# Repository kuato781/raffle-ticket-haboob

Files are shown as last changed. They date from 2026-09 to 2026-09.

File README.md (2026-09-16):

# Raffle Ticket Haboob

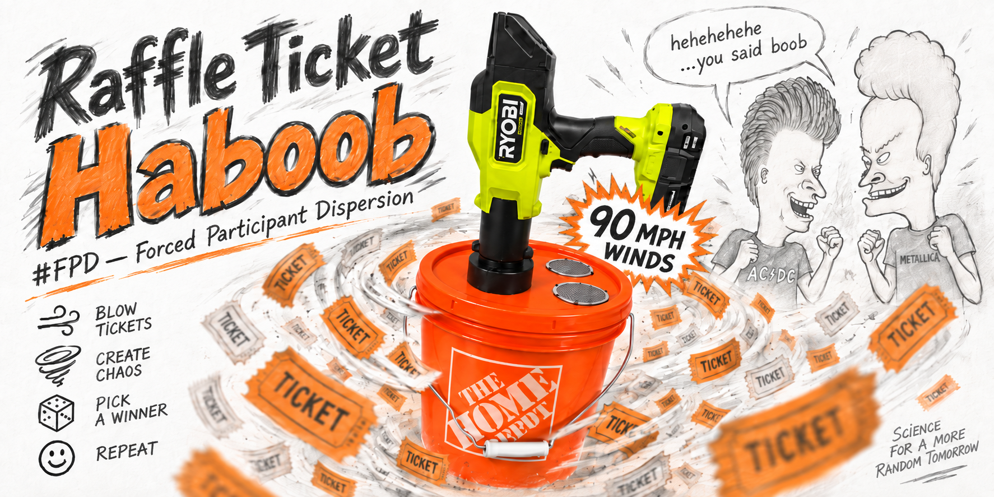
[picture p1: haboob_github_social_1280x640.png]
Raffle Ticket Haboob


A 3D-printed, blower-powered raffle-ticket mixer built around a 2-gallon bucket, a removable lid assembly, and a compact RYOBI cordless blower.

The goal is simple: break up the ticket clumps that survive ordinary bucket shaking and force the whole ticket mass into motion before a drawing.

The operating principle is **#FPD — Forced Participant Dispersion**.

In less formal engineering language: **fuck your clumps.**

## What It Does

The Haboob injects a high-volume air stream into a raffle bucket through a bayonet-style receiver mounted in the lid. Three screened exhaust openings allow air to escape while printed internal baffles reduce the tendency for tickets to plaster themselves directly against the screens.

The blower is used in short pulses rather than held continuously. Each pulse lifts and redistributes the ticket mass, then lets it settle before the next pulse.

The project was physically prototyped and iterated using actual raffle tickets, including internal video taken from inside the bucket during testing.

> **Airflow note:** The project artwork references **90 MPH winds**. That number is a rough idealized estimate of average air velocity through the approximately 2.25-inch receiver bore at 220 CFM. It is not a measured ticket velocity or a calibrated performance rating. The RYOBI blower itself is manufacturer-rated up to 140 MPH.

## Designed Blower

The receiver geometry was designed and physically fit-tested with the:

**RYOBI 18V ONE+ HP Compact Brushless 220 CFM Blower — model PSBLB01B**

- 220 CFM rated airflow
- up to 140 MPH manufacturer-rated airspeed
- product page: https://www.ryobitools.com/products/46396047137

Other blowers may work, but the bayonet receiver, bore, lug locations and clearances were designed around this specific tool. Using another blower may require changes to the receiver geometry.

## Major Components

The lid assembly consists of:

- threaded blower receiver;
- knurled underside locknut;
- removable bayonet storage plug;
- three round mesh vent screens;
- three internal anti-ingestion baffles;
- nine M2.5 × 4 mm button-head screws;
- nine M2.5 heat-set inserts;
- one reusable layout/drill template.

The removable threaded receiver and vent hardware allow the lid components to be taken off for storage so the buckets and lids can still nest/stack normally.

## Shopping List

| Item | Notes | Link |
|---|---|---|
| Round screen vent covers | Three per lid | https://www.amazon.com/gp/product/B0F9F76M15/ref=ox_sc_act_title_1 |
| M2.5 heat-set inserts | **M2.5 × 4 × 3.5** — M2.5 thread, 4 mm length, 3.5 mm OD | https://www.amazon.com/dp/B0F2N8QY45 |
| Awl | Useful for transferring template hole locations | https://www.amazon.com/dp/B0D6NJ2XSF |
| Hole saw set | Includes the required 2-1/2 in and 2-1/8 in sizes | https://www.harborfreight.com/34-in-to-5-in-carbon-steel-hole-saw-set-18-piece-57524.html |
| Home Depot orange 2-gallon bucket | Orange bucket option | https://www.homedepot.com/p/The-Home-Depot-2-gal-Orange-paint-Bucket-PN0192/321367180 |
| Home Depot orange lid | Matching orange lid | https://www.homedepot.com/p/2-Gal-Orange-Lid-RG502LHD/332526779 |
| Leaktite white 2-gallon bucket | White bucket option | https://www.homedepot.com/p/Leaktite-2-Gallon-White-Paint-Bucket-2GL-WHITE-PAIL/202264039 |
| Leaktite 2-gallon lid | Matching white lid | https://www.homedepot.com/p/Leaktite-2-gal-Bucket-Lid-210655/202264036 |
| M2.5 × 4 mm button-head screws | Nine per lid | Source locally or from your preferred hardware supplier |

See also: [`buy-list/README.md`](buy-list/README.md).

## Printed Parts

Current printable files are in [`stl-scad/`](stl-scad/):

- blower receiver;
- knurled locknut;
- bayonet storage plug;
- vent baffle;
- layout/drill template;
- editable OpenSCAD sources.

Exact current dimensions, clearances and the iteration history are documented in [`documentation/design-notes/README.md`](documentation/design-notes/README.md).

A Bambu Studio project is also included in [`bambu-sudio-3mf/`](bambu-sudio-3mf/).

The repository intentionally has **no V1/V2 directory split**. Unlike the Spektrum iX14 stand project, this project has one current physically validated design rather than parallel legacy/current versions.

## Lid Layout

### Receiver hole

Cut one **2-1/2 inch** hole for the blower receiver.

The tested layout places the receiver-hole center approximately **1-3/4 inches from the outside lid lip**.

### Vent holes

Cut three **2-1/8 inch** holes for the vent screens.

The included 82 mm layout/drill template is designed to make this repeatable:

1. Print **three templates** if possible.
2. Place all three templates flat-side-up on the lid.
3. Arrange them around the receiver location so the full 82 mm baffle footprints clear one another and have the spacing/orientation you want.
4. Mark the center hole in each template.
5. Cut the three 2-1/8 inch vent holes.
6. Flip the template over.
7. Insert the raised locating boss/lip into each finished vent hole.
8. Use the three guide holes to mark the M2.5 mounting screw locations.

Using the same template for both layout and bolt-hole transfer makes multiple lids much easier to reproduce with consistent geometry.

## Assembly

Detailed instructions are in [`documentation/assembly-instructions/README.md`](documentation/assembly-instructions/README.md).

High-level sequence:

1. Print the receiver, locknut, plug, three baffles and layout/drill templates.
2. Install the M2.5 heat-set inserts in the three bosses on each baffle.
3. Lay out and cut the 2-1/2 inch receiver hole.
4. Use three layout templates to establish the three 2-1/8 inch vent positions with enough clearance between the full baffle footprints.
5. Cut the three vent holes.
6. Flip/key the template into each finished vent hole and mark the three M2.5 screw holes.
7. Install the threaded receiver from the top and secure it below the lid with the knurled locknut.
8. Install the three round mesh vent screens.
9. Install one baffle beneath each vent using three M2.5 × 4 mm button-head screws.

The current baffle uses three heat-set-insert mounting bosses and a perimeter cage. The contact ribs intentionally stand slightly proud of the bosses so tightening the screws preloads the rib tops against the underside of the lid and reduces ticket-ingestion gaps.

## Operation

1. Make sure the lid is fully seated on the bucket.
2. For event use, adding duct tape around the lid/bucket seam is recommended as secondary retention.
3. Lock the blower into the bayonet receiver.
4. Keep the assembly stable and the lid restrained. If it can be done safely, steady downward pressure on the lid can help control movement, but **do not rely on hand pressure as the only lid-retention method**.
5. **Pulse** the blower rather than holding it continuously.
6. Let the tickets lift, circulate and settle between pulses.
7. Remove the blower when mixing is complete.

The airflow is intentionally substantial. Do not operate the system with an unsecured lid, damaged printed parts, loose hardware or bystanders positioned where a lid or loose component could strike them.

## Drawing Workflow

The baffle system greatly reduces tickets getting trapped against the vent screens, but the project is not intended to guarantee that absolutely zero tickets can ever lodge between a baffle and the lid.

Before a final drawing:

1. Open the bucket.
2. Inspect the underside of the lid and all three baffles.
3. Remove any ticket that may have lodged there and return it to the bucket.
4. Give the tickets one final manual stir.
5. Draw normally.

That last inspection/manual stir is the practical final safeguard against the occasional straggler.

## End-of-Day Storage

When the bucket is being stored with tickets still inside:

- remove the blower;
- install the bayonet plug in the receiver opening;
- confirm the lid is fully seated before moving or storing the bucket.

For compact storage after the event, the lid hardware can be removed and placed inside each bucket. The buckets and bare lids can then nest/stack into one another.

## Product Photos

Physical-build product images are in [`documentation/product-images/`](documentation/product-images/).

The set includes:

- receiver, locknut and plug;
- baffle and drill-template hardware;
- mesh vent screens;
- completed lid;
- assembled bucket;
- blower installed in the receiver;
- bucket with the storage plug installed.

A contact sheet is included as [`00-raffle-ticket-haboob-contact-sheet.png`](documentation/product-images/00-raffle-ticket-haboob-contact-sheet.png).

## Development / Test Videos

Internal testing videos are in [`documentation/videos/`](documentation/videos/):

- [`haboob-bottom-view.mov`](documentation/videos/haboob-bottom-view.mov)
- [`haboob-side-view.mov`](documentation/videos/haboob-side-view.mov)

The internal camera testing was deliberately low-tech: an iPhone was taped inside the bucket so the ticket behavior could be observed during actual blower operation.

Those tests exposed two useful problems that drove the final baffle design:

- tickets could plaster directly against the vent screens;
- tickets could sometimes slip into the gap between an early baffle and the lid.

The final larger baffle geometry clears the screen retaining tabs, uses a cage around the perimeter and adds mechanical preload against the lid.

## Development History

This project followed the same process as the other Arroyo 3D-printing projects:

**measure → model → print → physically test → revise**

The major progression was:

1. Prove that the RYOBI blower could lock into a printed receiver.
2. Convert the receiver to a removable threaded bulkhead so lids could still stack.
3. Add a removable bayonet plug for overnight/event storage.
4. Add three screened exhaust vents to relieve lid pressure.
5. Add simple standoff baffles after tickets were observed plastering against the screens.
6. Add a perimeter cage after tickets were observed entering the open annular gap.
7. Add heat-set inserts and screw mounting so baffle height would be repeatable instead of depending on hot glue.
8. Enlarge the baffle clear zone to avoid the four metal retaining tabs on the vent screens.
9. Add preload to the baffle contact ribs to reduce the remaining lid gap.
10. Convert the drill template into a two-sided layout/registration fixture so multiple lids can be built with repeatable spacing.

The current geometry has been physically tested with the actual bucket, screens, fasteners, inserts, tickets and RYOBI blower.

## AI-Assisted Design and Development

This project was developed with AI assistance.

AI was used to help:

- turn measurements and fit observations into printable geometry;
- iterate receiver, thread, bayonet, baffle and template designs;
- calculate rough airflow estimates;
- generate editable OpenSCAD sources and STL models;
- analyze physical-test results and revise the design;
- organize documentation and repository structure;
- clean up product photography and create project artwork.

The CAD was never treated as proof by itself. Physical fit, actual airflow behavior and event workflow got the final vote.

## Repository Organization

| Directory | Contents |
|---|---|
| `stl-scad/` | Current printable STL files plus editable OpenSCAD source |
| `bambu-sudio-3mf/` | Bambu Studio project file(s) |
| `buy-list/` | Shopping list and hardware requirements |
| `documentation/assembly-instructions/` | Detailed build and assembly procedure |
| `documentation/design-notes/` | Dimensions, clearances and development rationale |
| `documentation/product-images/` | Product photographs and contact sheet |
| `documentation/videos/` | Physical airflow/development test videos |

## Important Safety Information

This project combines 3D-printed parts, a high-output blower and a bucket lid that can become pressurized if airflow is restricted.

- Inspect all printed parts, heat-set inserts, screws, vent screens, receiver threads and bayonet features before use.
- Confirm that the lid is fully seated and positively retained before operating the blower.
- Never operate with blocked vents.
- Use short blower pulses rather than sustained operation.
- Keep faces, hands and bystanders out of any potential lid/component path.
- Stop immediately if the lid deforms excessively, hardware moves, the receiver loosens or any printed part cracks.
- Verify that your specific bucket, lid, blower and printed parts fit correctly before event use.
- Read [`DISCLAIMER.md`](DISCLAIMER.md) before building or operating the design.

This is an independent project and is not affiliated with or endorsed by RYOBI, Techtronic Industries, The Home Depot, Leaktite, Amazon or Harbor Freight.

## License

This project is provided under the [Creative Commons Attribution-NonCommercial 4.0 International License](LICENSE).

You may print, copy, share and modify the files for noncommercial purposes with attribution. Changes must be identified.

The original files and derivatives may not be sold or otherwise used commercially without separate permission from the creator.

## Why?

Because hand-shaking a bucket full of thin paper raffle tickets apparently wasn't enough.

So naturally the next step was:

**a cordless blower + custom bayonet hardware + threaded bulkhead + screened exhaust vents + anti-ingestion baffles + heat-set inserts + reusable drill fixtures + internal test footage.**

For a raffle bucket.

#FPD.

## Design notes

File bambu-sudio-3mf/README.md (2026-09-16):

# Bambu Studio Project

This directory contains the Bambu Studio project file(s) for the current Raffle Ticket Haboob parts.

Current project:

- `raffle_ticket_haboob_layout_drill_template_82mm_lipped_m25_v14.3mf`

The corresponding editable OpenSCAD and STL files live in [`../stl-scad/`](../stl-scad/).

Use the 3MF as a slicer starting point, but verify printer, material, layer height, wall count and other settings for your own machine before printing.

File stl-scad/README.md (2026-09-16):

# Printable CAD Files

This directory contains the current Raffle Ticket Haboob printable models and editable OpenSCAD sources.

## Current Parts

| Part | Purpose |
|---|---|
| `raffle_ticket_haboob_receiver_threaded.*` | Threaded blower receiver / lid bulkhead |
| `raffle_ticket_haboob_knurled_locknut.*` | Underside hand-tightened receiver locknut |
| `raffle_ticket_haboob_plug.*` | Bayonet storage plug for the receiver |
| `raffle_ticket_haboob_baffle.*` | Three-screw anti-ingestion vent baffle |
| `raffle_ticket_haboob_layout_drill_template.*` | 82 mm two-sided layout and screw-hole transfer template |

The `.scad` files are the editable source. The `.stl` files are ready to import into a slicer.

## Recommended Quantity

- receiver: 1
- locknut: 1
- plug: 1
- baffle: 3
- layout/drill template: ideally 3

Printing three templates is recommended because the full 82 mm disks can be arranged simultaneously on the lid before drilling. This makes the three baffle footprints easy to space consistently and prevents overlap.

## Design Details

See [`../documentation/design-notes/README.md`](../documentation/design-notes/README.md) for the current dimensions, clearances, insert geometry and design history.

## Blower Compatibility

The receiver was designed around the **RYOBI PSBLB01B 18V ONE+ HP Compact Brushless 220 CFM Blower**.

Other blowers may require modification of the receiver bore, bayonet slot/lug geometry or overall dimensions.

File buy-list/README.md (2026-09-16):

# Raffle Ticket Haboob — Shopping List

This is the hardware and tool list used for the physically tested build.

## Core hardware

| Qty | Item | Specification / notes | Link |
|---:|---|---|---|
| 1 | 2-gallon bucket | Home Depot orange option | https://www.homedepot.com/p/The-Home-Depot-2-gal-Orange-paint-Bucket-PN0192/321367180 |
| 1 | Matching lid | Home Depot orange lid | https://www.homedepot.com/p/2-Gal-Orange-Lid-RG502LHD/332526779 |
| 1 | Alternative 2-gallon bucket | Leaktite white option | https://www.homedepot.com/p/Leaktite-2-Gallon-White-Paint-Bucket-2GL-WHITE-PAIL/202264039 |
| 1 | Matching alternative lid | Leaktite white lid | https://www.homedepot.com/p/Leaktite-2-gal-Bucket-Lid-210655/202264036 |
| 3 | Round screen vent covers | One per exhaust opening | https://www.amazon.com/gp/product/B0F9F76M15/ref=ox_sc_act_title_1 |
| 9 | Heat-set inserts | **M2.5 × 4 × 3.5** — M2.5 thread, 4 mm length, 3.5 mm OD | https://www.amazon.com/dp/B0F2N8QY45 |
| 9 | Button-head screws | **M2.5 × 4 mm** | Use preferred hardware supplier |
| 1 | RYOBI compact blower | RYOBI 18V ONE+ HP Compact Brushless 220 CFM Blower, **PSBLB01B** | https://www.ryobitools.com/products/46396047137 |

## Tools

| Item | Use | Link |
|---|---|---|
| Awl | Transfer template center and screw-hole marks | https://www.amazon.com/dp/B0D6NJ2XSF |
| Hole saw set | Provides required 2-1/2 in and 2-1/8 in cutters | https://www.harborfreight.com/34-in-to-5-in-carbon-steel-hole-saw-set-18-piece-57524.html |
| Soldering iron / insert tool | Install M2.5 heat-set inserts | Use preferred tool |
| Drill | Cut lid holes and drill screw clearances | Use preferred tool |
| Deburring knife / file | Clean plastic edges after hole-saw cuts | Use preferred tool |

## Printed parts

Print from [`../stl-scad/`](../stl-scad/):

- 1 × threaded receiver
- 1 × knurled locknut
- 1 × bayonet plug
- 3 × vent baffles
- ideally 3 × layout/drill templates

Printing three layout templates is strongly recommended. It lets you place all three 82 mm baffle footprints on the lid simultaneously before cutting anything, which makes spacing repeatable and prevents adjacent baffles from colliding.

## Optional event-use supplies

- duct tape for secondary lid retention;
- spare M2.5 screws;
- spare heat-set inserts;
- spare printed plug;
- spare lid if you are building multiple raffle buckets.

## Notes

The receiver geometry was designed around the RYOBI PSBLB01B. Other blowers may require dimensional changes to the receiver bore, bayonet slots or locking-lug geometry.

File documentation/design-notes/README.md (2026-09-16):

# Raffle Ticket Haboob — Design Notes

This file captures the dimensions and design decisions behind the current parts in [`../../stl-scad/`](../../stl-scad/).

The editable OpenSCAD files remain the authoritative source for printable geometry.

## Blower Receiver

Current receiver source: [`raffle_ticket_haboob_receiver_threaded.scad`](../../stl-scad/raffle_ticket_haboob_receiver_threaded.scad)

Key dimensions:

| Feature | Dimension |
|---|---:|
| Receiver ID | 57.15 mm (2.25 in) |
| Receiver OD | 82.55 mm (3.25 in) |
| Receiver height | 30.0 mm |
| Bayonet lug diameter | 5.5 mm |
| Lug inward projection | 3.0 mm |
| Lug bottom height | 10.0 mm from receiver base |
| Thread major diameter | 62.4 mm |
| Thread depth | 0.8 mm |
| Thread pitch | 4.0 mm |
| Threaded neck length | 14.0 mm |

The upper receiver fit was established first and then intentionally preserved while the removable bulkhead/threaded mounting system was developed around it.

## Knurled Locknut

Current source: [`raffle_ticket_haboob_knurled_locknut.scad`](../../stl-scad/raffle_ticket_haboob_knurled_locknut.scad)

Key dimensions:

| Feature | Dimension |
|---|---:|
| Nominal receiver thread major diameter | 62.4 mm |
| Internal radial clearance | 0.35 mm |
| Thread pitch | 4.0 mm |
| Nut OD | 84.0 mm |
| Nut height | 10.0 mm |
| Knurl count | 40 |

The coarse thread was chosen for easy printing, easy hand assembly and tolerance of normal FDM surface variation.

## Vent Baffle

Current source: [`raffle_ticket_haboob_baffle.scad`](../../stl-scad/raffle_ticket_haboob_baffle.scad)

Key dimensions:

| Feature | Dimension |
|---|---:|
| Baffle OD | 82.0 mm |
| Solid deflector thickness | 2.5 mm |
| Central tab-clear diameter | 64.5 mm |
| Structural boss count | 3 at 120° |
| Boss center radius | 36.5 mm |
| Boss OD | 8.0 mm |
| Boss height | 12.7 mm |
| Rib preload above boss plane | 0.50 mm |
| Rib count positions | 18 total positions, with three omitted at bosses |
| Rib radial dimension | 4.0 mm |
| Rib tangential thickness | 2.2 mm |
| Rib center radius | 34.75 mm |
| Insert thread | M2.5 |
| Insert length | 4.0 mm |
| Insert OD | 3.5 mm |
| Insert pilot diameter | 3.2 mm |
| Insert pocket depth | 4.2 mm |
| Insert lead-in diameter | 3.6 mm |

### Why 64.5 mm of central clearance?

The physical metal vent-screen hardware has four retaining tabs. Their measured end-to-end span was approximately 63.8 mm.

Early three-boss baffles could land partially on those tabs, which propped one side of a baffle away from the lid and created a gap large enough for tickets to enter.

The final 64.5 mm clear diameter moves every baffle contact point outside the tab envelope while retaining the simpler three-screw mounting pattern.

### Why the ribs are taller than the bosses

Hot-glued prototypes revealed that very small uneven gaps were enough for a ticket edge to work between the baffle and lid.

The final screw-mounted design therefore makes the perimeter ribs **0.50 mm taller than the structural boss contact plane**. Tightening the three mounting screws preloads those rib tops against the lid and accommodates some normal lid waviness.

This does not produce a mathematically perfect seal; physical testing still produced an occasional trapped ticket. The event procedure therefore includes a final underside inspection and manual stir before drawing.

## Layout / Drill Template

Current source: [`raffle_ticket_haboob_layout_drill_template.scad`](../../stl-scad/raffle_ticket_haboob_layout_drill_template.scad)

Key dimensions:

| Feature | Dimension |
|---|---:|
| Template OD | 82.0 mm |
| Plate thickness | 3.0 mm |
| Vent-hole nominal diameter | 53.975 mm (2-1/8 in) |
| Locating boss/lip OD | 53.475 mm |
| Locating boss/lip height | 2.0 mm |
| Screw-hole center radius | 36.5 mm |
| Screw guide diameter | 2.8 mm |
| Center guide diameter | 2.8 mm |

The template intentionally performs two jobs:

1. **Flat side up:** three printed copies can be arranged simultaneously to represent the full baffle footprints and establish consistent vent spacing.
2. **Flipped over after cutting:** the 53.475 mm locating boss keys into each completed 2-1/8 in vent hole so the three screw-hole centers can be transferred concentrically.

This makes repeated lids much easier to build with nearly identical geometry.

## Storage Plug

Current source: [`raffle_ticket_haboob_plug.scad`](../../stl-scad/raffle_ticket_haboob_plug.scad)

Key dimensions in the repository source:

| Feature | Dimension |
|---|---:|
| Male stem OD | 56.20 mm |
| Stem length | 26.0 mm |
| Cap OD | 82.55 mm |
| Cap thickness | 5.0 mm |
| Slot width | 6.6 mm |
| Slot radial depth | 4.4 mm |
| Locking turn | 34° |
| Grip diameter | 34 mm |
| Grip height | 14 mm |

The plug uses the same pair of receiver lugs as the blower bayonet and gives the bucket a simple closure when the blower is removed overnight or between event days.

## Airflow Estimate

The project uses a blower rated at 220 CFM.

Treating the receiver as an ideal 2.25-inch circular flow area gives a rough average velocity on the order of **90 MPH**.

That calculation intentionally ignores losses, blower operating-point changes, turbulence, leakage, blockage, ticket loading and the actual nonuniform velocity profile. It is therefore useful only as an order-of-magnitude project description, not as a measured performance claim.

The blower manufacturer separately rates the tool up to 140 MPH.

## Development Sequence

The physical iterations were roughly:

1. Fit-test a simple receiver against the RYOBI bayonet.
2. Preserve that proven upper geometry and add a threaded removable neck.
3. Add the knurled underside locknut.
4. Add an end-of-day bayonet plug.
5. Cut screened exhaust vents in the lid.
6. Observe lid ballooning and tickets plastering against the screens.
7. Add simple mushroom-style deflector discs on standoffs.
8. Observe tickets entering through the open perimeter gap.
9. Add a perimeter cage.
10. Replace hot glue with three M2.5 heat-set insert bosses.
11. Discover interference between the three-boss pattern and the screen's four retaining tabs.
12. Enlarge the central no-contact zone to 64.5 mm.
13. Add stronger rib preload against the lid.
14. Turn the drill template into a full 82 mm two-sided layout/registration fixture.

The final design is the result of physical observation rather than CAD-only assumptions.

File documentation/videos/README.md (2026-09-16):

# Development / Airflow Test Videos

These videos show actual ticket behavior inside the Raffle Ticket Haboob during blower testing.

- [`haboob-bottom-view.mov`](haboob-bottom-view.mov) — bottom-oriented internal view
- [`haboob-side-view.mov`](haboob-side-view.mov) — side-oriented internal view

The test setup was intentionally simple: an iPhone was taped inside the bucket before the lid was installed and the blower was pulsed.

The footage helped identify two important behaviors that drove the final baffle design:

1. tickets could plaster directly against the exposed vent screens;
2. tickets could work into the gap between an early baffle and the lid.

Those observations led to the perimeter cage, the larger 64.5 mm screen-tab clearance zone, screw-mounted heat-set-insert bosses and additional rib preload against the underside of the lid.

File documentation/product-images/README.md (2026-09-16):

# Product Images

These images document the current physical Raffle Ticket Haboob build.

| File | Subject |
|---|---|
| `00-raffle-ticket-haboob-contact-sheet.png` | Contact sheet for the full image set |
| `01-mixer-receiver-nut-plug.png` | Printed receiver, knurled locknut and bayonet plug |
| `02-baffle-template.png` | Baffle and layout/drill-template hardware |
| `03-screens.png` | Round mesh vent screens |
| `04-lid.png` | Modified lid with receiver and vent screens |
| `05-bucket.png` | Completed bucket/lid assembly |
| `06-haboob.png` | RYOBI blower installed in the receiver |
| `07-plugged.png` | Bucket with bayonet storage plug installed |

The photos were cleaned to remove foam-board seams and distracting shadows while preserving the project hardware and retaining a natural studio contact shadow.

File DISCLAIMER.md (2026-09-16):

# Use at Your Own Risk

The design files, models, print profiles, instructions, photographs, videos and other materials in this repository are provided for personal, noncommercial use on an **as-is** and **as-available** basis.

## No warranty

No warranty or representation is made that the materials are accurate, complete, error-free, safe, suitable for a particular purpose or compatible with any specific printer, material, tool, blower, bucket, lid or application.

3D-printed parts can vary significantly because of printer calibration, filament condition, material selection, slicer settings, print orientation, layer adhesion, environmental exposure, assembly technique, hardware tolerances and normal wear.

This project also uses a high-output cordless blower and a bucket lid with restricted exhaust area. Incorrect assembly, blocked vents, loose hardware or an improperly retained lid can create hazardous movement or pressure.

## Your responsibility

You are solely responsible for determining whether the design is suitable for your intended use. Before relying on any printed part or procedure, you should:

- Review the design, dimensions, hardware and instructions.
- Confirm that your printer, material and slicer settings are appropriate.
- Inspect every print for cracks, poor layer adhesion, deformation or other defects.
- Verify the fit of the receiver, locknut, bayonet features, inserts, baffles, screens and fasteners.
- Confirm that all vents are unobstructed before operation.
- Confirm that the lid is fully seated and positively retained.
- Test the completed assembly in a controlled environment before event use.
- Use short blower pulses rather than sustained operation.
- Keep faces, hands and bystanders out of any potential path of the lid or loose components.
- Reinspect printed parts and hardware periodically and replace anything damaged, loose or worn.

Do not assume that another user's successful print or test guarantees that your copy will perform the same way.

## Airflow and performance claims

Any airflow figures in the repository beyond the blower manufacturer's published specifications are approximate engineering estimates for project discussion only.

The artwork reference to **90 MPH winds** is based on a rough idealized average velocity calculation through the receiver bore at the blower's nominal 220 CFM rating. It is **not** a measured ticket velocity, calibrated airflow measurement or safety rating.

## Assumption of risk

By downloading, printing, modifying, assembling or using these materials, you accept all associated risks. These may include failed prints, damaged tools or project materials, damaged equipment or property, loss of use and personal injury.

These materials are not professionally engineered, certified or tested as safety equipment. Do not use them for life-support, structural, emergency or other safety-critical applications.

## Raffle fairness

This project is intended to help redistribute raffle tickets before a drawing. It does not certify, guarantee or mathematically prove randomization, fairness, legal compliance or suitability for any regulated drawing.

Users are responsible for complying with their event rules, organization policies and applicable law.

## Limitation of liability

To the maximum extent permitted by applicable law, the creator and contributors will not be liable for any direct, indirect, incidental, special, consequential, exemplary or other loss, damage, cost or injury arising from the materials or their use, modification, assembly or inability to be used.

## Modifications and redistribution

If you modify or redistribute these materials, clearly identify your changes. You are responsible for validating your modified version and should preserve this disclaimer or provide an equivalent notice to downstream users.

## Trademarks and affiliations

RYOBI, ONE+, The Home Depot, Leaktite, Amazon, Harbor Freight and any other product or company names referenced in this repository are the property of their respective owners.

This is an independent project and is not affiliated with, sponsored by or endorsed by those companies.

## Relationship to the license

This disclaimer supplements the repository's [`LICENSE`](LICENSE) file and does not replace or modify its terms. If there is any conflict, the license controls.

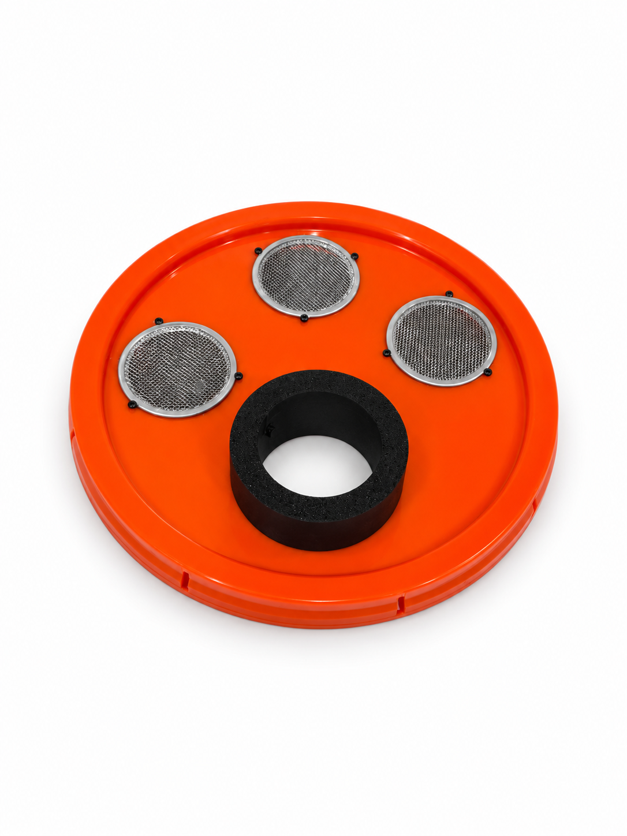
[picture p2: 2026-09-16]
documentation/product-images/04-lid.png

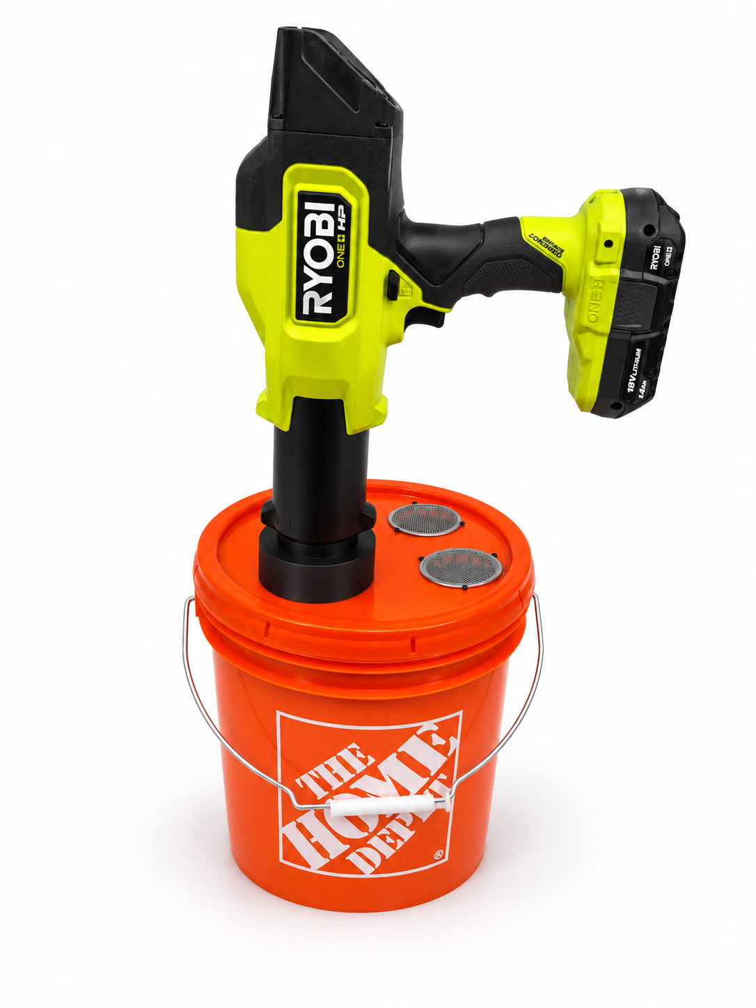
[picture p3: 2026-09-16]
documentation/product-images/06-haboob.png

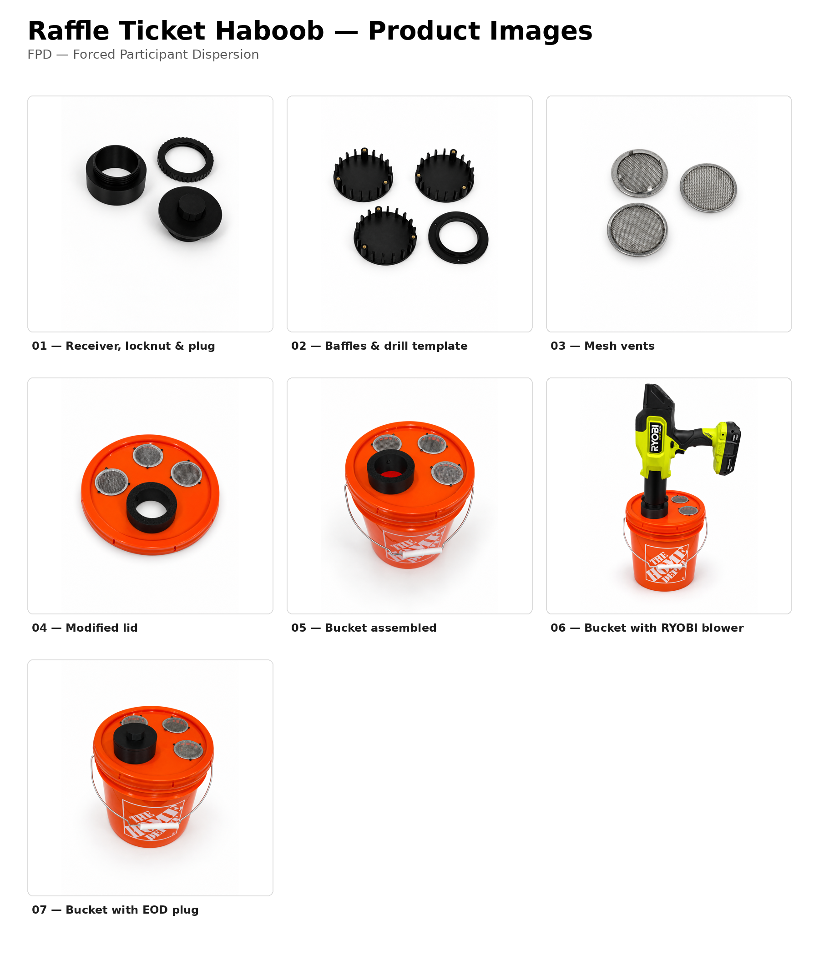
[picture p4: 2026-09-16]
documentation/product-images/00-raffle-ticket-haboob-contact-sheet.png

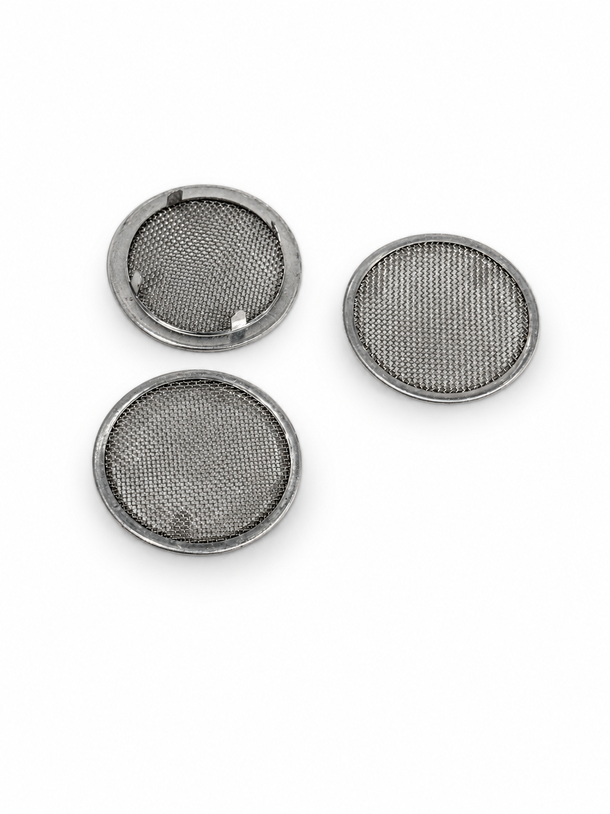
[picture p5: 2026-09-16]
documentation/product-images/03-screens.png

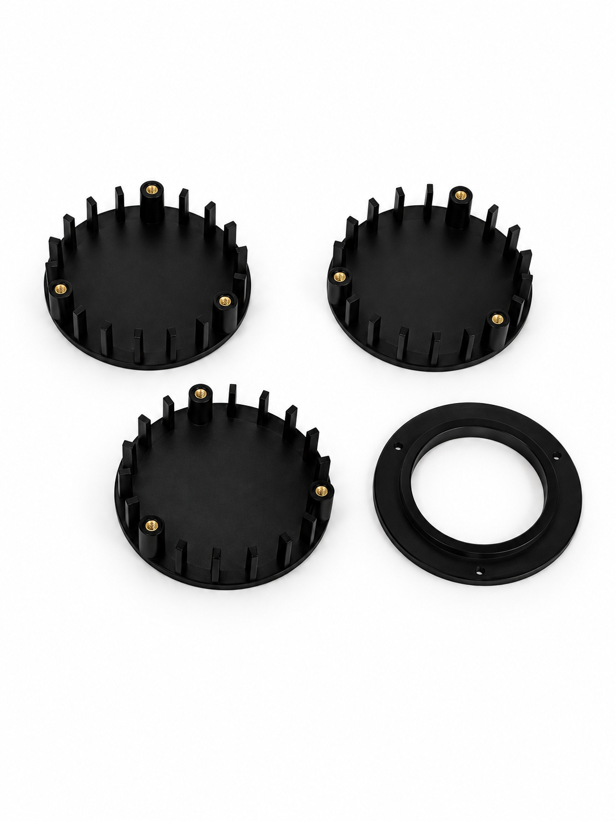
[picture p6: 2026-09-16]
documentation/product-images/02-baffle-template.png

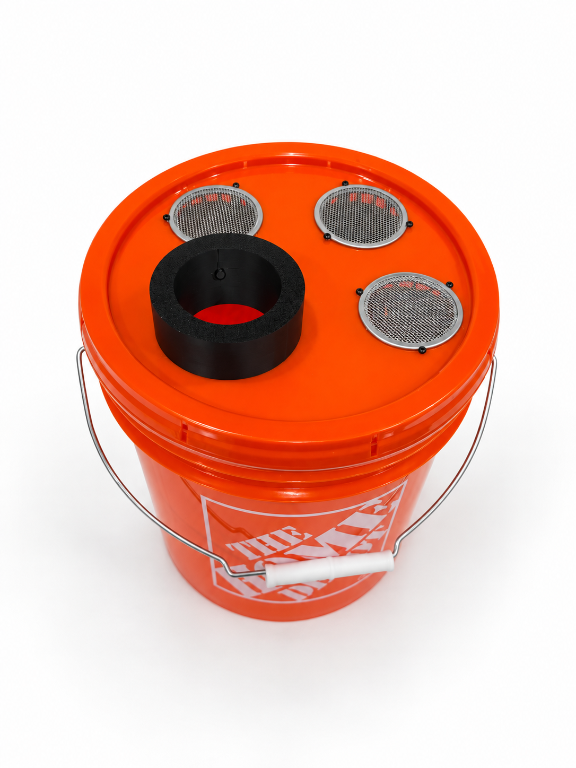
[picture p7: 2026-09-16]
documentation/product-images/05-bucket.png

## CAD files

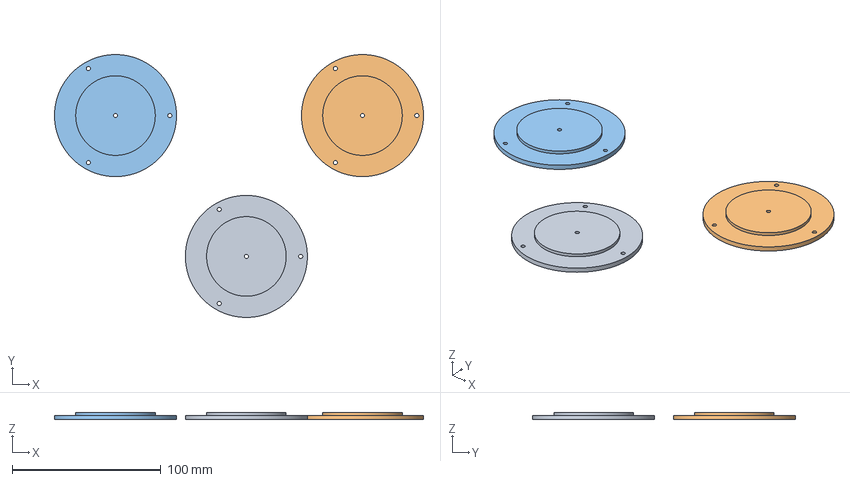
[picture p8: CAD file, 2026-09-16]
bambu-sudio-3mf/raffle_ticket_haboob_layout_drill_template_82mm_lipped_m25_v14.3mf
248.0 x 176.7 x 5.00 mm
raffle_ticket_haboob_layout_drill_template_82mm_lipped_m25_v14.stl x 3

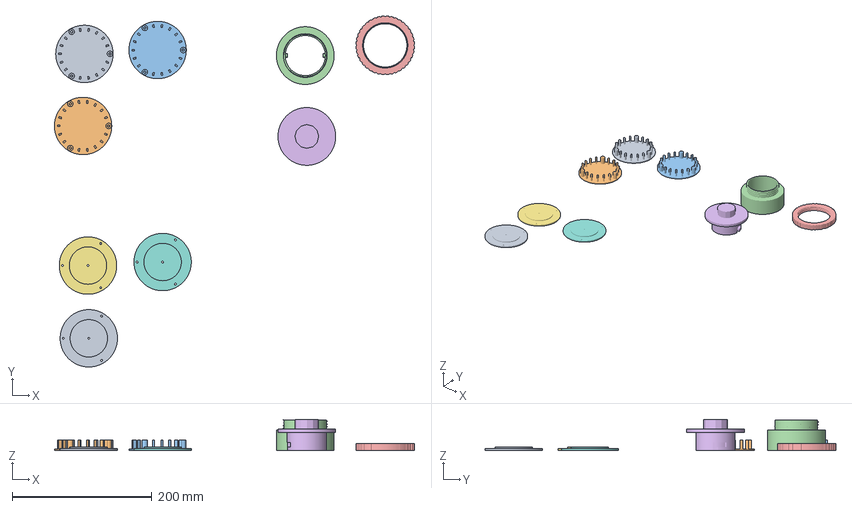
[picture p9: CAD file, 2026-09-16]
stl-scad/raffle_ticket_haboob copy.3mf
514.8 x 501.6 x 45.0 mm
raffle_ticket_haboob_baffle.stl x 3
raffle_ticket_haboob_receiver_threaded.stl
raffle_ticket_haboob_knurled_locknut.stl
raffle_ticket_haboob_plug.stl
raffle_ticket_haboob_layout_drill_template.stl x 3

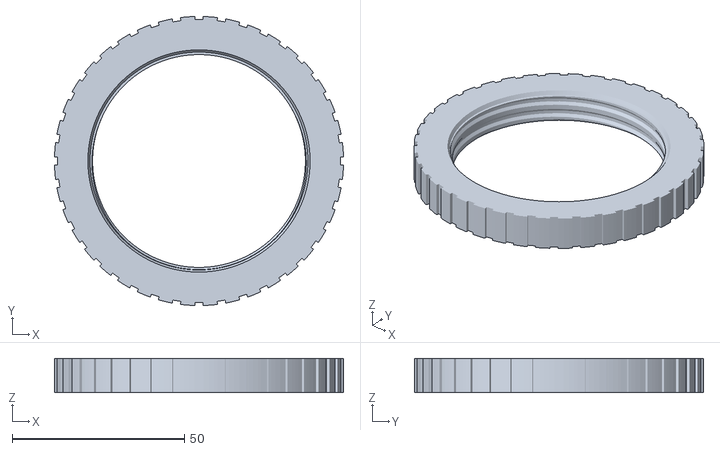
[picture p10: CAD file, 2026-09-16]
stl-scad/raffle_ticket_haboob_knurled_locknut.stl
84.0 x 84.0 x 10.0

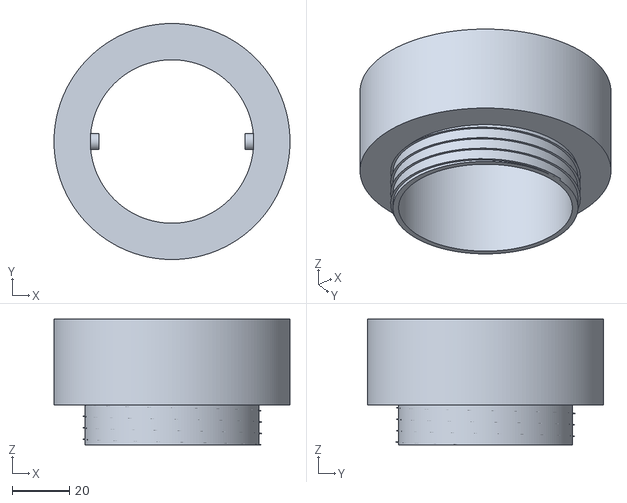
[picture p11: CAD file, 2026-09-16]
stl-scad/raffle_ticket_haboob_receiver_threaded.stl
82.5 x 82.5 x 44.0

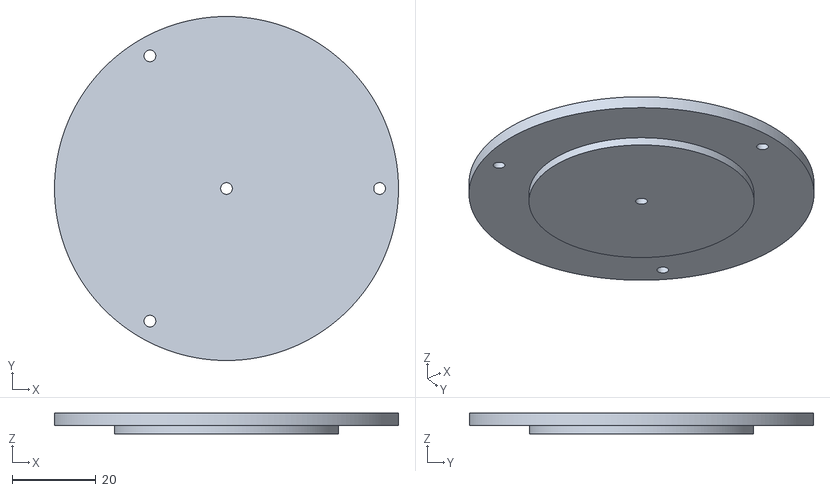
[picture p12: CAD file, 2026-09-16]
stl-scad/raffle_ticket_haboob_layout_drill_template.stl
82.0 x 82.0 x 5.00

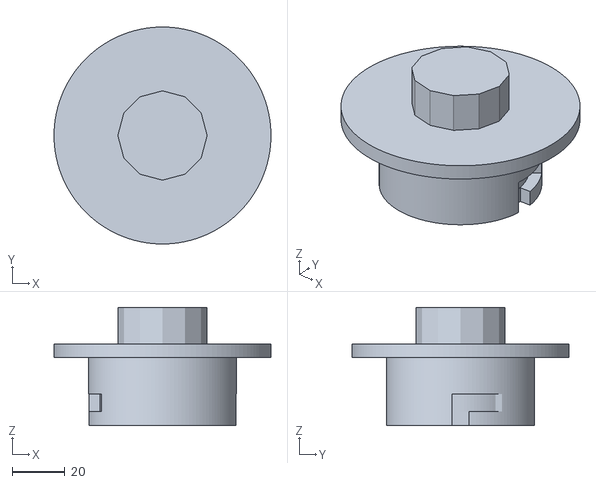
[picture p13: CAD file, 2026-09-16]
stl-scad/raffle_ticket_haboob_plug.stl
82.5 x 82.5 x 45.0

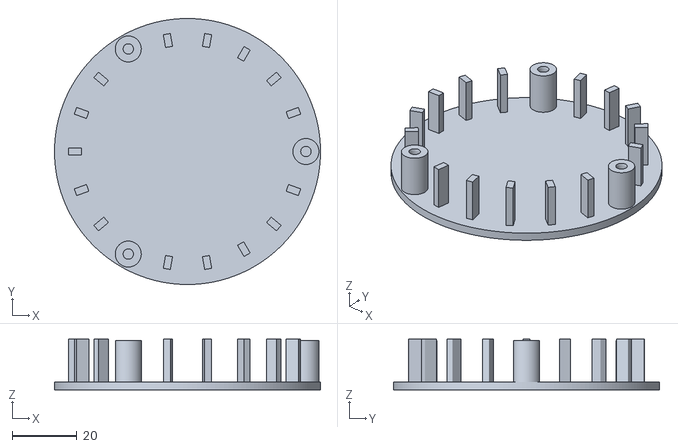
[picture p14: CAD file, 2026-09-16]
stl-scad/raffle_ticket_haboob_baffle.stl
82.0 x 82.0 x 15.7

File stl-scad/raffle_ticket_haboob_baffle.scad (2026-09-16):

// Raffle Ticket Haboob vent baffle v1.4
// 82 mm OD, 64.5 mm tab-clear zone, 3x M2.5 heat-set inserts
// v1.4: correct M2.5 x 4 x 3.5 insert geometry (4 mm length, 3.5 mm OD)
//       tighter heat-set pilot so insert does not fall through

$fn=180;

disc_d=82.0;
disc_th=2.5;

clear_id=64.5;
clear_r=clear_id/2;

boss_h=12.7;
rib_preload=0.50;       // ribs extend this much above boss contact plane
rib_h=boss_h+rib_preload;

rib_count=18;
rib_radial=4.0;
rib_tangent=2.2;
rib_radius=34.75;

boss_count=3;
boss_radius=36.5;
boss_od=8.0;

// M2.5 x 4.0 mm length x 3.5 mm OD heat-set insert pocket
// 3.2 mm pilot provides material for heat-set displacement; shallow lead-in centers insert.
insert_pocket_d=3.2;
insert_pocket_depth=4.2;
insert_leadin_d=3.6;
insert_leadin_h=0.6;

module structural_boss(angle=0){
    rotate([0,0,angle])
        translate([boss_radius,0,disc_th-0.25])
            difference(){
                cylinder(h=boss_h+0.25,d=boss_od);
                translate([0,0,boss_h+0.25-insert_pocket_depth])
                    cylinder(h=insert_pocket_depth+0.25,d=insert_pocket_d);
                translate([0,0,boss_h+0.25-insert_leadin_h])
                    cylinder(h=insert_leadin_h+0.25,d1=insert_pocket_d,d2=insert_leadin_d);
            }
}

union(){
    // Solid airflow-deflector disc
    cylinder(h=disc_th,d=disc_d);

    // Thin anti-ingestion ribs. Skip the three boss locations.
    // Start 0.20 mm into the disc so all ribs form one manifold solid.
    for(i=[0:rib_count-1]){
        if(i!=0 && i!=6 && i!=12)
            rotate([0,0,i*360/rib_count])
                translate([rib_radius,0,disc_th-0.20+(rib_h+0.20)/2])
                    cube([rib_radial,rib_tangent,rib_h+0.20],center=true);
    }

    // Three structural screw/insert bosses at 120 degrees.
    for(i=[0:boss_count-1])
        structural_boss(i*120);
}

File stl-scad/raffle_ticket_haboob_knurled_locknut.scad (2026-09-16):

$fn=180;

// Raffle-Ticket Hurricane / FPD
// Matching knurled locknut v0.3
// Units: mm

thread_major_d=62.4;
thread_depth=0.8;
thread_pitch=4.0;

radial_clearance=0.35;
internal_major_d=thread_major_d+2*radial_clearance;
internal_depth=thread_depth+0.10;
internal_core_d=internal_major_d-2*internal_depth;

nut_od=84.0;
nut_h=10.0;

knurl_count=40;
knurl_width=2.4;

module internal_thread_cutter() {
    r_minor = internal_core_d/2;
    tooth_w = thread_pitch*0.68;

    union() {
        translate([0,0,-0.2])
            cylinder(h=nut_h+0.4,d=internal_core_d);

        linear_extrude(
            height=nut_h,
            twist=360*nut_h/thread_pitch,
            slices=180,
            convexity=14
        )
        translate([r_minor-0.30,0])
        polygon(points=[
            [0,-tooth_w*0.30],
            [internal_depth+0.30,-tooth_w*0.14],
            [internal_depth+0.30, tooth_w*0.14],
            [0, tooth_w*0.30]
        ]);
    }
}

module knurled_body() {
    difference() {
        cylinder(h=nut_h,d=nut_od);

        for(i=[0:knurl_count-1]) {
            rotate([0,0,i*360/knurl_count])
                translate([nut_od/2+0.8,0,nut_h/2])
                    cube([3.4,knurl_width,nut_h+1],center=true);
        }
    }
}

difference() {
    knurled_body();
    internal_thread_cutter();

    translate([0,0,-0.15])
        cylinder(h=1.3,d1=internal_major_d+1.4,d2=internal_major_d);

    translate([0,0,nut_h-1.15])
        cylinder(h=1.3,d1=internal_major_d,d2=internal_major_d+1.4);
}

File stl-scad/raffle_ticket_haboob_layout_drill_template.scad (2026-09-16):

// Raffle Ticket Haboob baffle layout / drill template v1.4
// Solid 82 mm footprint disk + underside locating lip.
// Workflow:
// 1) Print three copies and arrange all three on lid to establish spacing.
// 2) Use center guide holes to mark 2-1/8 in vent-hole centers.
// 3) Cut vent holes.
// 4) Reinsert template using underside lip to key concentrically in each vent hole.
// 5) Mark/drill three M2.5 mounting holes.

$fn=180;

template_od = 82.0;
plate_th = 3.0;

// Existing lid vent hole: 2-1/8 in = 53.975 mm.
// 0.50 mm diametral clearance gives an easy slip fit while remaining well-centered.
vent_hole_d = 53.975;
locating_lip_d = 53.475;
locating_lip_h = 2.0;

// Matches baffle structural boss centers.
boss_radius = 36.5;

// Guide holes sized for marking / pilot drilling.
guide_hole_d = 2.8;
center_guide_hole_d = 2.8;

module template_body(){
    union(){
        // Main solid footprint disk.
        cylinder(h=plate_th, d=template_od);

        // Underside locating plug/lip. This keys into the completed 2-1/8 in vent hole.
        // It is intentionally a solid circular plug (except for the center guide hole),
        // because the template itself is now used to transfer bolt-hole locations.
        translate([0,0,-locating_lip_h])
            cylinder(h=locating_lip_h+0.02, d=locating_lip_d);
    }
}

difference(){
    template_body();

    // Center guide remains available both before and after cutting the vent hole.
    translate([0,0,-locating_lip_h-0.2])
        cylinder(h=plate_th+locating_lip_h+0.4, d=center_guide_hole_d);

    // Three M2.5 screw-guide locations at 120 degrees.
    for(i=[0:2]){
        rotate([0,0,i*120])
            translate([boss_radius,0,-0.2])
                cylinder(h=plate_th+0.4, d=guide_hole_d);
    }
}

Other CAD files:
stl-scad/raffle_ticket_haboob_plug.scad
stl-scad/raffle_ticket_haboob_receiver_threaded.scad

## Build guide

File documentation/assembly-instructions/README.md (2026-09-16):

# Raffle Ticket Haboob — Assembly Instructions

These instructions describe the current physically tested Raffle Ticket Haboob build.

## Before You Start

Read the root [`DISCLAIMER.md`](../../DISCLAIMER.md) first.

The tested build uses:

- one 2-gallon bucket and matching lid;
- RYOBI PSBLB01B compact blower;
- one printed threaded receiver;
- one printed knurled locknut;
- one printed bayonet plug;
- three printed vent baffles;
- ideally three printed layout/drill templates;
- three round mesh vent screens;
- nine M2.5 × 4 × 3.5 heat-set inserts;
- nine M2.5 × 4 mm button-head screws.

The templates, baffles, receiver, locknut and plug are in [`../../stl-scad/`](../../stl-scad/).

## 1. Print the Parts

Print:

- 1 × `raffle_ticket_haboob_receiver_threaded`
- 1 × `raffle_ticket_haboob_knurled_locknut`
- 1 × `raffle_ticket_haboob_plug`
- 3 × `raffle_ticket_haboob_baffle`
- 3 × `raffle_ticket_haboob_layout_drill_template` if possible

Three templates are recommended because they let you see the actual 82 mm footprint of all three baffles before drilling the lid.

Inspect every print for cracks, layer-separation, malformed threads or incomplete holes before assembly.

## 2. Install the Heat-Set Inserts

Each baffle has three mounting bosses.

Install one **M2.5 × 4 × 3.5** heat-set insert into each boss, for nine inserts total.

The current insert pocket is intentionally smaller than the insert OD so the insert should not simply fall into the hole. It should sit at the opening and require heat to be pressed into position.

Guidelines:

1. Heat the insert with a soldering iron or insert-installation tip.
2. Keep it square to the boss.
3. Press it slowly into the pocket.
4. Stop when the insert is seated without bulging or splitting the boss.
5. Allow the plastic to cool before installing screws.

## 3. Mark the Receiver Hole

The tested receiver-hole location places the hole center approximately **1-3/4 inches from the outside lid lip**.

Mark the center carefully.

Before drilling, confirm that the proposed receiver location leaves enough room for all three 82 mm vent/baffle footprints.

## 4. Lay Out the Three Vent/Baffle Locations

Use the layout templates **before cutting the vent holes**.

1. Place three templates **flat-side-up** on the lid.
2. Arrange them around the receiver location.
3. Confirm that the full 82 mm template disks do not overlap one another or interfere with the receiver area.
4. Rotate and space the templates until the layout looks clean and repeatable.
5. Use an awl or marker through each center hole to mark the three vent centers.

Because the template OD matches the baffle footprint, this step prevents the common failure mode of putting two vent holes so close together that the installed baffles collide.

## 5. Cut the Lid Holes

Cut:

- **1 × 2-1/2 inch hole** for the blower receiver;
- **3 × 2-1/8 inch holes** for the vent screens.

Use appropriate eye protection and support the lid so the hole saw does not grab or distort it excessively.

Deburr the cut edges after drilling.

## 6. Transfer the Baffle Screw Holes

The same template is used again after the vent holes are cut.

1. Flip the template over.
2. Insert the raised locating boss/lip into one finished 2-1/8 inch vent hole.
3. Confirm that the template sits flat and centered.
4. Mark all three M2.5 screw locations through the guide holes.
5. Repeat for the other two vent holes.
6. Drill the marked screw holes with an appropriate clearance drill for the M2.5 screws.

This two-sided process gives you both coarse layout and precise concentric mounting-hole transfer from the same fixture.

## 7. Install the Threaded Receiver

1. Insert the threaded receiver through the 2-1/2 inch lid hole from the top.
2. Thread the knurled locknut onto the receiver from the underside.
3. Tighten it firmly enough to clamp the lid without crushing or badly distorting the plastic.
4. Confirm that the receiver cannot rotate freely in the lid.

The receiver is removable by design so the hardware can be taken off for compact storage.

## 8. Install the Mesh Vent Screens

Install one round screen vent cover over each 2-1/8 inch vent hole.

Make sure:

- the screen sits flat;
- the four metal retaining tabs are fully engaged;
- no tab protrudes into a position that prevents the baffle from seating correctly.

The final baffle geometry includes a clear central zone designed to clear the measured screen retaining tabs.

## 9. Install the Three Baffles

Mount one baffle beneath each screen using three M2.5 × 4 mm button-head screws.

The current baffle has:

- three structural insert bosses at 120°;
- a perimeter cage to reduce ticket ingestion;
- a large central clear zone for the screen tabs;
- perimeter contact ribs that sit slightly taller than the structural bosses.

That extra rib height creates preload against the underside of the lid when the screws are tightened.

Tighten the screws evenly. Do not crank them down hard enough to strip inserts, crush the lid or distort the baffle.

## 10. Fit-Test the Plug

Insert the bayonet plug into the receiver and rotate it into the locking position.

It should:

- enter cleanly;
- rotate into engagement with both internal lugs;
- sit snugly enough not to rattle excessively;
- remain removable by hand.

Use the plug when the bucket is stored with tickets inside and the blower is removed.

## 11. Fit-Test the Blower

With the bucket empty:

1. Lock the RYOBI PSBLB01B into the receiver.
2. Verify engagement with both bayonet lugs.
3. Confirm that the receiver and locknut do not rotate in the lid.
4. Confirm all three vent paths are open.
5. Remove the blower before continuing.

Do not assume a different blower will fit. The receiver geometry was designed around the PSBLB01B.

## 12. Controlled Airflow Test

Before event use, perform a controlled test with a small ticket load.

1. Add a modest number of tickets.
2. Fully seat the lid.
3. Add secondary retention such as duct tape around the lid/bucket seam if desired.
4. Lock the blower into the receiver.
5. Stabilize the assembly.
6. Use only short blower pulses.
7. Watch for excessive lid ballooning, unusual movement, blocked vents, loose fasteners or tickets repeatedly lodging around one baffle.
8. Stop immediately if anything appears unsafe or mechanically loose.

The goal is not to hold the blower continuously. The intended action is:

**pulse → tickets lift/circulate → release → tickets settle → repeat**

## 13. Event-Day Use

1. Confirm the lid is fully seated.
2. Use secondary retention around the lid seam if desired.
3. Lock in the blower.
4. Keep the bucket stable.
5. Use short pulses to redistribute the tickets.
6. Remove the blower when mixing is complete.

If downward hand pressure on the lid is used to steady the assembly, do so only when your hand is in a safe position and **never treat hand pressure as the sole lid-retention method**.

## 14. Final Draw Procedure

The final baffle design greatly reduces ticket trapping, but the tested build can still occasionally leave a ticket lodged between a baffle and the lid.

Immediately before the draw:

1. Open the bucket.
2. Inspect all three baffles and the underside of the lid.
3. Remove any stuck ticket and return it to the bucket.
4. Give the ticket mass one final manual stir.
5. Draw normally.

This is the recommended practical safeguard for the remaining rare edge case.

## 15. End-of-Day Storage

If tickets remain in the bucket overnight or between event days:

1. Remove the blower.
2. Install the bayonet plug in the receiver.
3. Confirm the lid is fully seated before moving or storing the bucket.

For compact storage after the event:

1. Remove the receiver and locknut.
2. Remove the vent/baffle hardware if desired.
3. Put the removable hardware inside the bucket.
4. Nest the buckets and lids normally.

## Validation Status

The current build has been physically tested with:

- the actual RYOBI PSBLB01B blower;
- 2-gallon bucket/lid hardware;
- the printed threaded receiver and locknut;
- the printed bayonet plug;
- three round vent screens;
- the current three-screw baffle design;
- M2.5 heat-set inserts and button-head screws;
- real raffle tickets;
- internal side-view and bottom-view video during blower operation.

The current geometry is considered the production design for this repository.

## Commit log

2026-09-16 Project files uploaded
    [raffle_ticket_haboob copy.3mf, raffle_ticket_haboob_baffle.scad, raffle_ticket_haboob_baffle.stl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]
2026-09-16 Add detailed assembly and operation instructions
2026-09-16 Document printable part files
